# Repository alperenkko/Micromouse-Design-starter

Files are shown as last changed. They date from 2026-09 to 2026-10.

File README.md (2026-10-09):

# Micromouse - Autonomous Maze Solving Robot

An autonomous Micromouse robot that is  capable of navigating and solving a maze with high speed and efficiency with custom 3D-printed suction components.

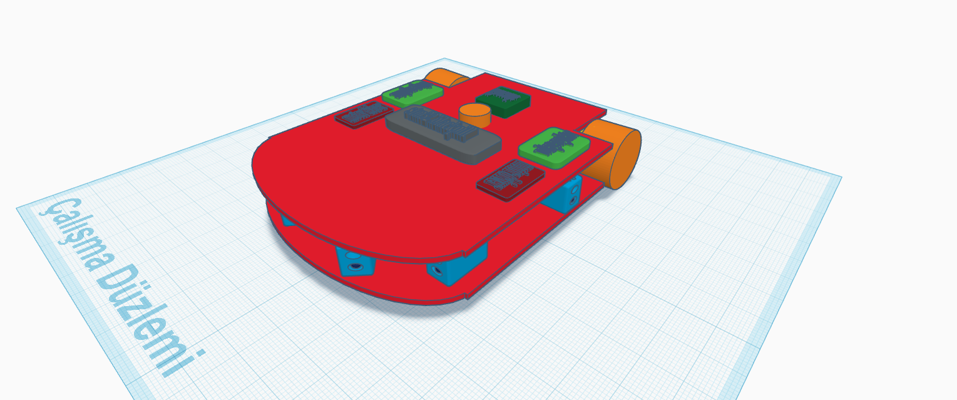
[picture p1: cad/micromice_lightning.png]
Micromouse CAD Preview


---

## Features
The Complex algorithms, the PID tuning and 6 Fully-Custom IR sensors. It compares the value between two sensors to center itself in the middle of the maze cell. theres 2 side (90°) and 2 front (0°) sensors that it can use(2 corner sensors too). Also, it uses a complex algorithm that even has floodfill implemented inside to find the closest/most efficient exit possible. When tuned right with the PID and the signal values such as sensor values and PWM for the motors, this robot can slide in mazes like a wet soap in your hand, but with one exception; theres no crashes that make you sad!

---

## Technical Overview
Brain: STM32 Blackpill Microcontroller for sensor data acquisition and motor control,
Motors: N20 12mm 2000rpm encoder motors.
Wheels: 21x14mm jsumo silicone wheels for maximum grab and control over the corner-turns.
motor drivers: TB66FNG motor driver
Impeller fan: 720 coreless motor and 30-mm wide 9-wing impeller for ~50gr of suction power
6 Fully-Custom IR sensors: They work in analog voltage so you can sense even one centimeter if you make it good enough!💯

---

## Hardware & PCB Design

The image below shows the layout of the custom PCB designed in KiCad:
(it was so hard to do those since it was my first time lol)
---


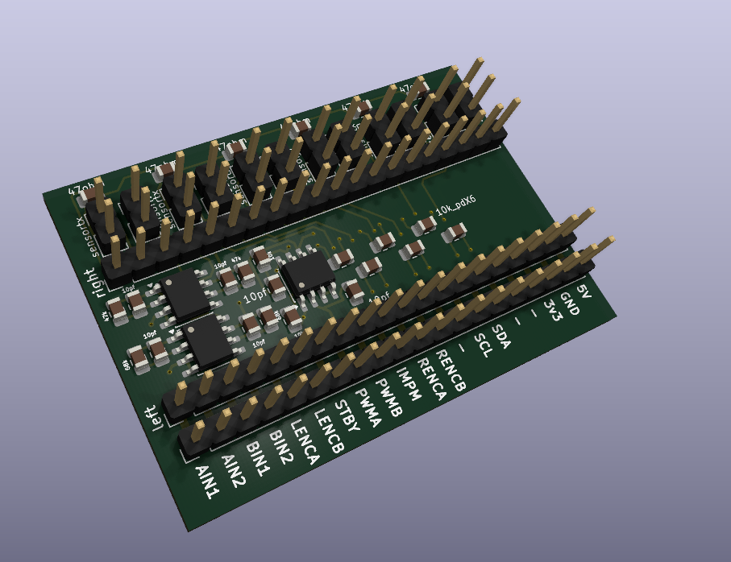
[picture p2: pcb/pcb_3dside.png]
PCB 3d view

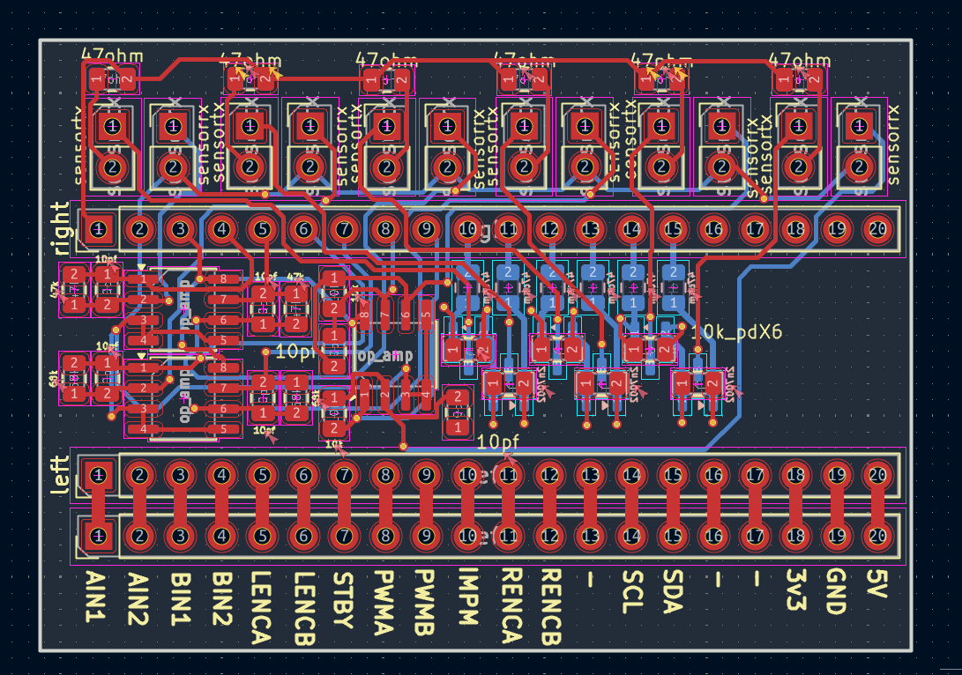
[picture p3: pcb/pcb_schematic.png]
PCB Layout


## Repository Structure
`/cad` contains all STL files (chassis, impeller, and motor mounts)
`/pcb` contains the KiCad schematic and PCB board file such as png and .kicad files.
`/firmware` contains the STM32 source-code for PID motor control, IR sensing and the Floodfill algorithm(read down there)

---

## Bill of Materials (BOM)
- [BOM.csv](bom/BOM.csv) - The main BOM file 
- [BOM_ozdisan.csv](bom/BOM_ozdisan.csv) - The BOM file for the custom IR sensor 
- [BOM_ozdisan.pdf](bom/BOM_ozdisan.pdf) - The PDF version / datasheet for the custom IR sensor (The pdf version of the IR sensor file.(downloaded from the website, its raw and half turkish.)

## /firmware folder
the code uses the STM32 library on ArduınoIDE to code the blackpill board using arduino IDE. heres the link of the library so you can download it too:
https://github.com/stm32duino/BoardManagerFiles/raw/main/package_stmicroelectronics_index.json
also, dont forget that this is just  a test/first code and NOT  the actual code since this project is still in the design.

---

thanks for reading, i think thats all i can do, i would be really happy if you approve it- also nothing here is AI Generated, i used AI just fore research and did everything myself. :) see you!!

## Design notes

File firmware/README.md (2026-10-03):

This Readme File is made for the /firmware folder. in this folder, you can see the skeleton of the code that i will use on the robot. its on .ino format so it uses ArduinoIDE program. i downloaded the library for the stm32 boards to test this on. thanks for reading.

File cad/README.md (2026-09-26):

# CAD & Mechanical Designs of the Project Micromouse

This folder contains the 3D mechanical models, CAD source files, and 3D-printable STL files for the Micromouse project (designed in Autodesk Fusion 360).

### File Structure & Descriptions are written in here:

#### 1. Vacuum Fan Assembly (Suction System)
* **`impeller_blade.step` / `impeller_blade.stl`**: 9-vane backward-curved 30mm impeller designed for high-RPM airflow and optimal downforce with a 720 coreless motor.
* **`impeller_bracket.step` / `impeller_bracket.stl`**: Vacuum casing housing with an integrated 7.15mm press-fit motor mount and 3 mounting legs for chassis integration.

#### 2. Full Chassis & Robot Design
* **`micromice_lightning.step`**: Complete assembly STEP file of the Micromouse robot chassis.
* **`micromice_lightning CAD.png`**: High-resolution 3D preview render of the robot design.

Thanks for reading, Alperen here :)

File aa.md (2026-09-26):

# Micromouse - Autonomous Maze Solving Robot

An autonomous Micromouse robot capable of navigating and solving a maze with high speed and efficiency with custom 3D-printed suction components.

Micromouse CAD Preview
---

## Motivation & Project Goal
I am an 11th-grade student at a Turkish high school with interests in robotics and PCB design. I created this project over the course of the past three months to test my knowledge of control systems, algorithms, and my own custom hardware design capabilities. My goal is to design and make a high-performance Micromouse robot that is capable of competing against the fastest Maze Solving Robots with the help of suction assistance, and optimized algorithms.
---

## Features & Technical Overview
Autonomous Navigation: Implemented the Floodfill Algorithm for calculating the shortest maze path
Closed-Loop Control: PID control with motor encoders and 6-axis gyroscope for precise wall centering and 90-degree turns.
Custom Sensing: Integrated 6 custom IR sensor modules for distance calculation and wall tracking(check kicad file)
Aerodynamic Suction: Custom 3D-printed impeller and mount (designed in Fusion 360) to create additional downforce
Brain: STM32 Blackpill Microcontroller for sensor data acquisition and motor control
---

## Hardware & PCB Design

The image below shows the layout of the custom PCB designed in KiCad:



If you are viewing this repo directly, please replace this text with a screenshot preview of your PCB layout/schematic!
---

## Repository Structure
`/cad` contains all STL files (chassis, impeller, and motor mounts)
`/pcb` contains the KiCad schematic and PCB board file.
`/firmware` contains the STM32 source-code for PID motor control, IR sensing and the Floodfill algorithm.
---

## Bill of Materials (BOM)
[BOM.csv](bom/BOM.csv) - The main BOM file
[BOM.csv](bom/BOM_ozdisan.csv)  - The BOM file for the custom IR sensor
[BOM.csv](bom/BOM_ozdisan.pdf)  - The pdf version of the IR sensor file.(downloaded from the website, its raw and half turkish.)

thanks for reading, i think thats all i can do, i would be really happy if you approve it- also nothing here is AI Generated, i used AI just fore research and did everything myself i think. :) see you!!

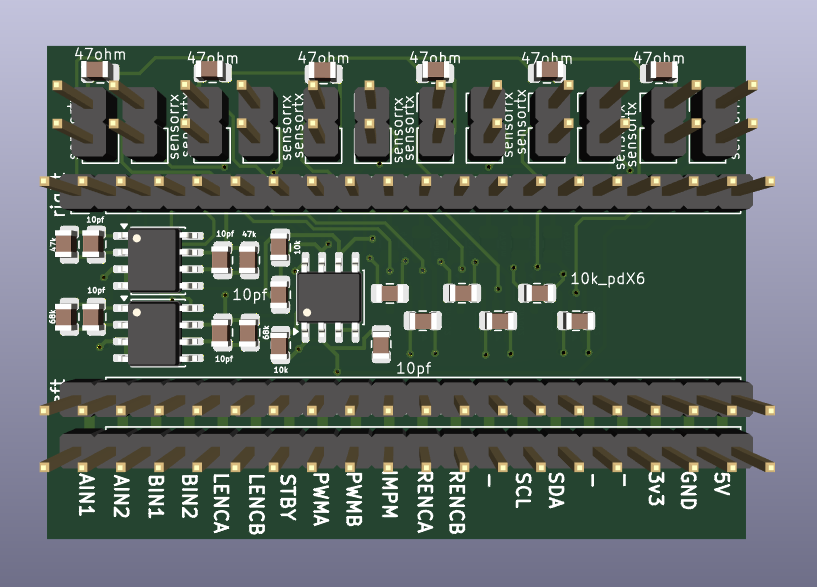
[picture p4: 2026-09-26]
pcb/pcb_3dtop.png

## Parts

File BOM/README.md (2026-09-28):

# Bill of Materials (BOM)

This folder that i wrote  contains the complete Bill of Materials for the Micromouse project.
The newer files contain the final versions such as the v2 design of the circuit, the newer BOM file and the new cart thats full of the new components!

### File Descriptions:
* **`BOM.csv`**: Main component list including the processor board, gyroscope/IMU, wheels, and core hardware. *(Required for the grant request)*.
* **`BOM_ozdisan.csv`**: Component list for the custom-designed IR sensor module (featuring analog voltage output, ambient light protection, and noise filtering).
* **`BOM_ozdisan.pdf`**: Local supplier quotation in Turkish Lira (TRY) for the IR sensor parts, including a $5 shipping estimation.
Thanks for Reading!

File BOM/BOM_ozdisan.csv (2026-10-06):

Item | Part Number | Manufacturer | Description | Quantity | Unit Price (USD) | Total Price Inc VAT (USD)
1 | FYL-5012PD1C-TR8.3 | FORYARD | PHOTO DIODE 20MA 5MM BLUE TAPE REEL SIZE 8.3 | 8 | 0.11123 | 1.07
2 | LTE-4208 | LITEON | LED INFRARED 5MM LITEON | 8 | 0.12858 | 1.23
3 | 2N7002_R1_00001 | PANJIT | MOSFET DIS.250mA 60V N-CH SOT23 SMT | 10 | 0.01735 | 0.21
4 | TLV9062IDR | TEXAS | IC-9062 OPAMP GP RR 10MHZ 8SOIC | 10 | 0.60879 | 7.31
5 | AC0805KRX7R9BB104 | YAGEO | MLCC (2012) 0805 100nF 50VDC 10% X7R AEC-Q200 SMT | 40 | 0.03953 | 1.9
6 | CL21C220JBANNNC | SAMSUNG | MLCC (2012) 0805 22pF 50VDC 5% COG (NPO) SMT | 10 | 0.01212 | 0.15
7 | 0805S8F470JTDE | ROYALOHM | RES. (2012) 0805 47 Ohms 1% 1/8WS -200PPM | 50 | 0.00239 | 0.14
8 | CQ0558F4702T5E | ROYALOHM | RES.(2012) 0805 47K Ohms 1% 1/8W-S AUTOMOTIV | 100 | 0.00188 | 0.23
9 | 080558J0103T5E | ROYALOHM | RES.(2012) 0805 10K Ohms 5% 1/8W-S 100PPM | 100 | 0.00153 | 0.18
10 | 080558J0101T5E | ROYALOHM | RES.(2012) 0805 100 Ohms 5% 1/8W-S 200PPM | 100 | 0.00153 | 0.18
11 | 080558J0102T5E | ROYALOHM | RES.(2012) 0805 1K Ohms 5% 1/8W-S 100PPM | 100 | 0.00153 | 0.18
12 | 080558J0683T5E | ROYALOHM | RES.(2012) 0805 68K Ohms 5% 1/8W-S 100PPM | 100 | 0.00153 | 0.18
13 | 080558F680JT5E | ROYALOHM | RES.(2012) 0805 68 Ohms 1% 1/8W-S 200PPM | 100 | 0.00182 | 0.22
14 | SS14_R1_00001 | PANJIT | DIODE SCHOTTKY 1A 40V DO214AC (SMA) Single SMT | 5 | 0.02936 | 0.18
15 | CC0805JRNPO9BN100 | YAGEO | MLCC (2012) 0805 10pF 50VDC 5% COG (NPO) SMT | 10 | 0.01784 | 0.21
16 | RC0805JR-07100KL | YAGEO | RES.(2012) 0805 100K Ohms 5% 1/8W 100PPM SMT | 50 | 0.0037 | 0.22
17 | CL21A106ΚΑΥΝNNE | SAMSUNG | MLCC (2012) 0805 10uF 25VDC 10% X5R SMT | 10 | 0.03316 | 0.4
18 | DS1021-1X40SF11-B | CONNFLY | PIN HEADER 40PIN(1x40) 2.54mm THT V/T | 2 | 0.12992 | 0.31
Total Amount | $24.00 | - | $24 | $24 | - | -

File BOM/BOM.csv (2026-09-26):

Item Name | Quantity | Total Price(USD) | Item Link
stm32f411ceu6 board | 1 | $11,50 | https://www.motorobit.com/stm32f411ceu6-black-pill-100mhz-512kb-development-board
TB6612FNG dual motor driver board | 2 | $4,80 | https://www.robocombo.com/tb6612fng-cift-motor-surucu-karti
NOVAMAX 2000rpm N20 12mm encoder motor | 2 | $23,80 | https://www.robotzade.com/urun/novamax-enkoderli-6v-2000rpm-mikro-dc-motor
JSUMO 2114 (21x14mm) silicone wheel set | 1 | $9,60 | https://www.robotus.net/js2114-silikon-tekerlek-seti
JSUMO 2114 wheel silicones | 1 | $7,90 | https://www.robotus.net/silikon-disi-js2114-1-cift
LSM6DS3 Accelerometer and gyroscope module | 1 | $9,60 | https://www.robocombo.com/lsm6ds3-ivmeolcer-ve-jiroskop-sensor-modulu-4617
QTR-1A Sensor Module(x2) | 1 | $10,00 | https://www.direnc.net/qtr-1rc-kizilotesi-dijital-sensor-paketi--2-adet-pololu?language=tr&h=363482f6
Profuse 2S 450mah lipo battery | 1 | $23,00 | https://www.robotsepeti.com/profuse-2s-74v-lipo-li-po-lityum-polimer-batarya-450mah-40c
Mini360 2A voltage regulator | 2 | $5,00 | https://www.robotistan.com/2a-mini-ayarlanabilir-voltaj-dusurucu-regulator-karti?language=tr&h=ed713a74
720 coreless drone motor(x4 in the set) | 1 | $5,00 | https://www.robocombo.com/720-cekirdeksiz-mikro-drone-motoru-2-cift-cwccw-4046
IR sensor components | 1 | $20,00 | BOM_ozdisan.csv/.pdf file(read)
Custom PCB (MOQ is 5, sorry) | 5 | $24,00 | https://www.onwaypcb.com/anasayfa
3d Printing of the case& sensor brackets | 1 | $10 | a website that can print it or a shop ( i couldnt found one theyre all making me wait or just some AI)
Total Amount Requested: | 1 | $171,70 | the total amount of money requested

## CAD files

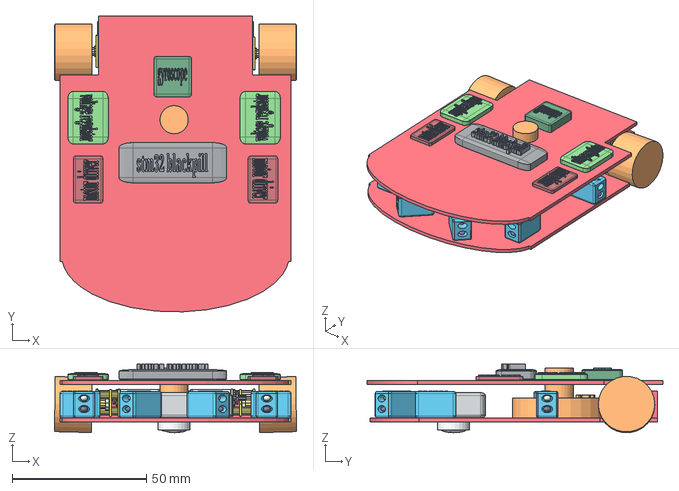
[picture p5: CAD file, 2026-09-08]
cad/micromouse robot_final.step
90.0 x 110.0 x 25.5 mm

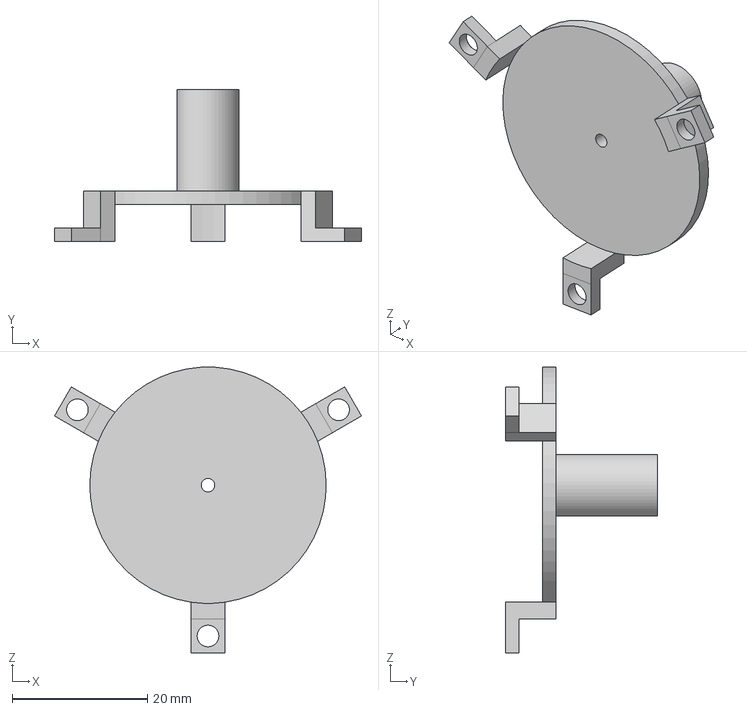
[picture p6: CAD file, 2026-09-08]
cad/impeller_bracket.step
45.5 x 22.5 x 42.3 mm

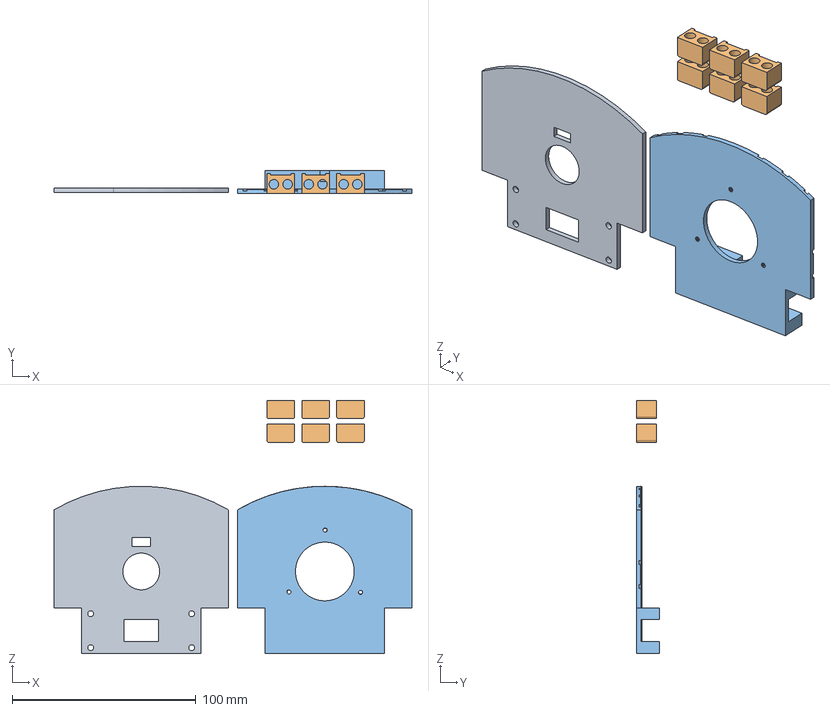
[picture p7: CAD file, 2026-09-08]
cad/micromice_body.step
195.0 x 12.5 x 138.0 mm

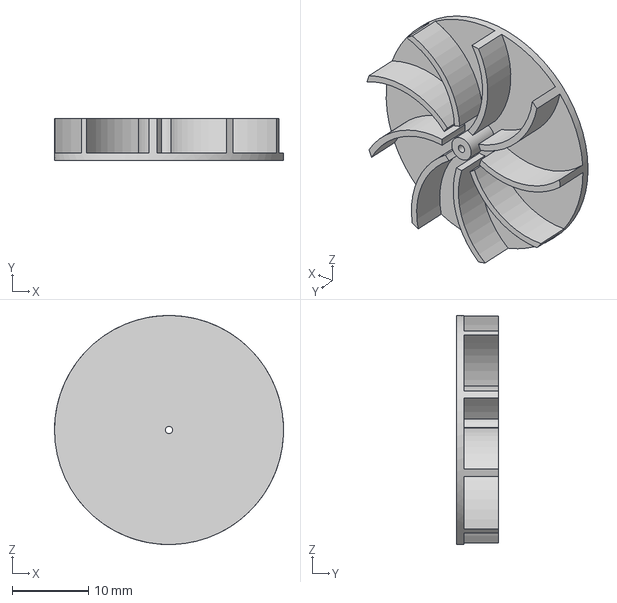
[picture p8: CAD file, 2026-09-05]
cad/impeller_blade.step
30.0 x 5.50 x 30.0 mm

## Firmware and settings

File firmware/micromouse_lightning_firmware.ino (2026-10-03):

#include <Arduino.h>
#include <Wire.h>

#define LSM6DS3_ADDR 0x6B

#define M_L_PWM PA11
#define M_R_PWM PA12

#define M_L_IN1 PB12
#define M_L_IN2 PB13
#define M_R_IN1 PB14
#define M_R_IN2 PB15

#define M_STBY  PA_10

#define IR_1 PA_0
#define IR_2 PA_1
#define IR_3 PA_2
#define IR_4 PA3
#define IR_5 PA4
#define IR_6 PA5

#define LED_MOSFET_1 PA6
#define LED_MOSFET_2 PA7
#define LED_MOSFET_3 PB_0
#define LED_MOSFET_4 PB_1
#define LED_MOSFET_5 PB_2
#define LED_MOSFET_6 PB10

const int FRONT_THRESHOLD = 600;
const int SIDE_THRESHOLD  = 400;

int16_t gyroZ_raw = 0;
float gyroZ_offset = 0;
float current_angle = 0;
unsigned long prev_time = 0;

int ir_val[6];

void setMotors(int left_pwm, int right_pwm) {
  if (left_pwm >= 0) {
    digitalWrite(M_L_IN1, HIGH);
    digitalWrite(M_L_IN2, LOW);
    analogWrite(M_L_PWM, constrain(left_pwm, 0, 255));
  } else {
    digitalWrite(M_L_IN1, LOW);
    digitalWrite(M_L_IN2, HIGH);
    analogWrite(M_L_PWM, constrain(-left_pwm, 0, 255));
  }

  if (right_pwm >= 0) {
    digitalWrite(M_R_IN1, HIGH);
    digitalWrite(M_R_IN2, LOW);
    analogWrite(M_R_PWM, constrain(right_pwm, 0, 255));
  } else {
    digitalWrite(M_R_IN1, LOW);
    digitalWrite(M_R_IN2, HIGH);
    analogWrite(M_R_PWM, constrain(-right_pwm, 0, 255));
  }
}

void stopMotors() {
  analogWrite(M_L_PWM, 0);
  analogWrite(M_R_PWM, 0);
  digitalWrite(M_L_IN1, LOW);
  digitalWrite(M_L_IN2, LOW);
  digitalWrite(M_R_IN1, LOW);
  digitalWrite(M_R_IN2, LOW);
}

void readGyro() {
  Wire.beginTransmission(LSM6DS3_ADDR);
  Wire.write(0x22);
  Wire.endTransmission(false);
  Wire.requestFrom((uint8_t)LSM6DS3_ADDR, (size_t)2, true);

  if (Wire.available() >= 2) {
    uint8_t lsb = Wire.read();
    uint8_t msb = Wire.read();
    gyroZ_raw = (int16_t)((msb << 8) | lsb);
  }

  unsigned long now = micros();
  float dt = (now - prev_time) / 1000000.0;
  prev_time = now;

  float gyroZ_dps = (gyroZ_raw - gyroZ_offset) * 0.070;
  
  if (abs(gyroZ_dps) > 0.5) { 
    current_angle += gyroZ_dps * dt;
  }
}

void calibrateGyro() {
  long sum = 0;
  int valid_samples = 0;
  
  for (int i = 0; i < 500; i++) {
    Wire.beginTransmission(LSM6DS3_ADDR);
    Wire.write(0x22);
    Wire.endTransmission(false);
    Wire.requestFrom((uint8_t)LSM6DS3_ADDR, (size_t)2, true);
    if (Wire.available() >= 2) {
      uint8_t lsb = Wire.read();
      uint8_t msb = Wire.read();
      sum += (int16_t)((msb << 8) | lsb);
      valid_samples++;
    }
    delay(2);
  }
  if (valid_samples > 0) {
    gyroZ_offset = (float)sum / valid_samples;
  }
}

void turnDegrees(float target_deg, int speed) {
  current_angle = 0;
  prev_time = micros();

  if (target_deg > 0) {
    setMotors(speed, -speed);
    while (current_angle < target_deg) {
      readGyro();
      delayMicroseconds(500);
    }
  } else {
    setMotors(-speed, speed);
    while (current_angle > target_deg) {
      readGyro();
      delayMicroseconds(500);
    }
  }
  stopMotors();
}

void turnLeft90(int speed) {
  turnDegrees(-90.0, speed);
}

void turnRight90(int speed) {
  turnDegrees(90.0, speed);
}

void turn180(int speed) {
  turnDegrees(180.0, speed);
}

void readSensors() {
  ir_val[0] = analogRead(IR_1);
  ir_val[1] = analogRead(IR_2);
  ir_val[2] = analogRead(IR_3);
  ir_val[3] = analogRead(IR_4);
  ir_val[4] = analogRead(IR_5);
  ir_val[5] = analogRead(IR_6);
}

void setup() {
  pinMode(M_L_PWM, OUTPUT);
  pinMode(M_R_PWM, OUTPUT);
  pinMode(M_L_IN1, OUTPUT);
  pinMode(M_L_IN2, OUTPUT);
  pinMode(M_R_IN1, OUTPUT);
  pinMode(M_R_IN2, OUTPUT);
  pinMode(M_STBY, OUTPUT);

  digitalWrite(M_STBY, HIGH);

  pinMode(LED_MOSFET_1, OUTPUT);
  pinMode(LED_MOSFET_2, OUTPUT);
  pinMode(LED_MOSFET_3, OUTPUT);
  pinMode(LED_MOSFET_4, OUTPUT);
  pinMode(LED_MOSFET_5, OUTPUT);
  pinMode(LED_MOSFET_6, OUTPUT);

  digitalWrite(LED_MOSFET_1, HIGH);
  digitalWrite(LED_MOSFET_2, HIGH);
  digitalWrite(LED_MOSFET_3, HIGH);
  digitalWrite(LED_MOSFET_4, HIGH);
  digitalWrite(LED_MOSFET_5, HIGH);
  digitalWrite(LED_MOSFET_6, HIGH);

  pinMode(IR_1, INPUT);
  pinMode(IR_2, INPUT);
  pinMode(IR_3, INPUT);
  pinMode(IR_4, INPUT);
  pinMode(IR_5, INPUT);
  pinMode(IR_6, INPUT);

  Wire.setSCL(PB6);
  Wire.setSDA(PB7);
  Wire.begin();
  delay(100); 

  Wire.beginTransmission(LSM6DS3_ADDR);
  Wire.write(0x11);
  Wire.write(0x8C); 
  Wire.endTransmission(true);

  calibrateGyro();
  prev_time = micros();
}

void loop() {
  readSensors();
  readGyro();

  if (ir_val[2] > FRONT_THRESHOLD || ir_val[3] > FRONT_THRESHOLD) {
    if (ir_val[0] < SIDE_THRESHOLD && ir_val[1] < SIDE_THRESHOLD) {
      turnLeft90(120);
    } else if (ir_val[4] < SIDE_THRESHOLD && ir_val[5] < SIDE_THRESHOLD) {
      turnRight90(120);
    } else {
      turn180(120);
    }
  } else {
    setMotors(120, 120);
  }

  delay(5);
}

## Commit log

2026-09-04 added the BOM list for the sensor parts, nolink :/
    [BOM for özdisan.csv]
2026-09-04 BOM file for özdisan sensor parts
2026-09-04 added cad.png for vieving the project
2026-09-05 the .step file (3d design) for the robot.
    there might be some mistakes, its my first time doing 3d modeling, please give me a chance to make this dream real :)
    [micromice lightning.step]
2026-09-05 the stl and step files for the impeller
    720 type coreless motor compatible and press fit
    [impeller blade.step, impeller blade.stl, impeller bracket.step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]
2026-09-05 Rename impeller blade.step to cad/impeller blade.step
    [impeller blade.step]
2026-09-05 Rename impeller blade.stl to cad/impeller blade.stl
    [impeller blade.stl]
2026-09-05 Rename impeller bracket.step to cad/impeller bracket.step
    [impeller bracket.step]
2026-09-05 Rename impeller bracket.stl to cad/impeller bracket.stl
    [impeller bracket.stl]
2026-09-05 Rename micromice lightning CAD.png to CAD/micromice lightning CAD.png
2026-09-05 Rename micromice lightning.step to cad/micromice lightning.step
    [micromice lightning.step]
2026-09-05 Rename micromice lightning CAD.png to micromice lightning CAD.png
2026-09-05 Create README.md for the cad
2026-09-05 Update README with day 3 progress and CAD files
    Added updates for day 3, including STL files for the impeller and bracket.
2026-09-05 README for CAD project details
    Added a README file explaining the CAD project and its components.
2026-09-05 Rename BOM for özdisan.csv to BOM/BOM for özdisan.csv
    [BOM for özdisan.csv]
2026-09-05 Rename BOM sensor ozdisan.pdf to BOM/BOM sensor ozdisan.pdf
2026-09-05 Add README.md for BOM folder documentation
    Added README.md to describe the BOM folder contents and files.
2026-09-05 Revise README for BOM clarity and details
    Updated the README to provide a clearer overview of the Bill of Materials for the Micromouse project, including detailed file descriptions and features.
2026-09-05 Rename BOM sensor ozdisan.pdf to BOM_sensor_ozdisan.pdf
2026-09-05 Rename BOM for özdisan.csv to BOM_for_özdisan.csv
    [BOM_for_özdisan.csv]
2026-09-05 Revise README for CAD project details
    Updated README to provide detailed descriptions of CAD files and project structure.
2026-09-05 Rename impeller blade.step to impeller_blade.step
    [impeller_blade.step]
2026-09-05 Rename impeller bracket.stl to impeller_bracket.stl
    [impeller_bracket.stl]
2026-09-05 Rename impeller bracket.step to impeller_bracket.step
    [impeller_bracket.step]
2026-09-05 Rename impeller blade.stl to impeller_blade.stl
    [impeller_blade.stl]
2026-09-05 Rename micromice lightning CAD.png to micromice_lightning_CAD.png
2026-09-05 Rename micromice lightning.step to micromice_lightning.step
    [micromice_lightning.step]
2026-09-06 Add CAD preview image to README
    Added a preview image for the Micromouse CAD design.
2026-09-06 made a new version of the files.
    the BOM list got updated, added total amount etc.
    [BOM.csv, BOM_ozdisan.csv]
2026-09-06 Update BOM file names for consistency
2026-09-08 Changed some fi
    [gövde.step, gövde.stl, impeller_bracket.step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]
2026-09-08 added the 3d model of the final design robot
    [micromouse robot_final.step]
2026-09-26 added the last version of the IR sensor BOM list
2026-09-26 Added the final version of the Bill of Materials
    [BOM.csv]
2026-09-26 Added the PCB files
    [micromouse_pcb.kicad_pcb]
2026-09-26 carried the pcb files into the /pcb folder
    [micromouse_pcb.kicad_pcb]
2026-09-26 Update README with PCB link and project details
    Added PCB file link and project background information.
2026-09-26 Fix PCB file link in README
    Updated PCB file link to point to the correct repository location.
2026-09-26 added png files of the pcb design.
2026-09-26 Update README with PCB images
    Added 3D view and layout images of the PCB.
2026-09-26 Replace PCB layout image with schematic image
    Updated PCB layout image reference in README.
2026-09-28 added the schematic file
    [micromouse_pcb.kicad_sch]
2026-10-03 Revise BOM section in README for clarity
    Updated the Bill of Materials section for clarity and corrected the description of the PDF version of the IR sensor file.
2026-10-03 added the .csv version of the BOM_ozdisan file.
    [BOM_ozdisan.csv]
2026-10-06 Add descriptions to BOM_ozdisan.csv
    Updated BOM file to include descriptions for each item.
    [BOM_ozdisan.csv]
2026-11-07 Revise README.md for improved documentation
    Updated the README.md to include required library setup, key features, technical overview, hardware design, and bill of materials. Enhanced clarity and organization of content.
2026-11-07 add schematic screenshot
2026-11-07 Rename Ekran görüntüsü 2026-11-07 121356.png to schematic_preview.png
2026-11-07 Update schematic image reference in README
2026-11-09 add final cad and photo
